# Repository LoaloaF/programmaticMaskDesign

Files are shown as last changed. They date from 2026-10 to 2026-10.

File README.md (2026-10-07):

# programmaticMaskDesign

Code that generates photomask layouts for the MEA1K flexible-electronics wafers: the
devices themselves, and their arrangement on a 100 mm wafer. Everything is generated from
parameters; nothing on a wafer is drawn by hand except where noted.

```
programmaticMaskDesign/
  MEA1K_wafer4_12x_8x_8x_breakoutboards_Rev2.gds   the fabricated interconnect wafer (Rev2)
  InterconnectGeneration/      MEA1K chip <-> Molex connector interconnects
    HANDOVER.md
    build_designs.py           all five wafer designs of a revision (Rev2, Rev3)
    WaferNesting/              interconnect wafers: nest, reproduce Rev2, build Rev3
      HANDOVER.md
  generative_probe_design/     flexible 64-channel electrode probes
    README.md
    electrode_bundle/HANDOVER.md
    WaferNesting/README.md     probe wafers: count-maximising nest, mark inversion, wafer map
```

| Project | Makes | Start with |
|---|---|---|
| `InterconnectGeneration/` | the 12-block / 8-block interconnect DXFs and the dummy test structures | [`InterconnectGeneration/HANDOVER.md`](InterconnectGeneration/HANDOVER.md) |
| `InterconnectGeneration/WaferNesting/` | interconnect wafers; rebuilds the Rev2 wafer geometry-identically | [`InterconnectGeneration/WaferNesting/HANDOVER.md`](InterconnectGeneration/WaferNesting/HANDOVER.md) |
| `generative_probe_design/` | electrode-probe DXFs from design specs, and their wafers | [`generative_probe_design/README.md`](generative_probe_design/README.md) |

## The fabricated wafer

`MEA1K_wafer4_12x_8x_8x_breakoutboards_Rev2.gds` — 4 × 12-block, 4 × 8-block `51_35`,
4 × 8-block `71_15`, 26 dummies. It is reproduced from `InterconnectGeneration/designs/`:

```bash
cd InterconnectGeneration
export WAFERNEST_CONFIG=config_rev2
KL=/Applications/KLayout/klayout.app/Contents/MacOS/klayout
$KL -b -r WaferNesting/01c_extract_exact_placements.py
$KL -b -r WaferNesting/01d_rebuild_wafer.py      # ends with GEOMETRY IDENTICAL
```

The GDS layer numbers on it are the hand-renumbered ones (Metal1 7, Polyimide_Negative +
EtchingPad 3, Etching + Via 5, Metal2 6); see `InterconnectGeneration/WaferNesting/HANDOVER.md` §4.2.

## Rev3

The same wafer — every piece at its Rev2 position — with a revised pad stack on all five
designs: the final PI etch is no longer one square per pad but 5 µm etch vias around the pad
perimeter (15–20 µm apart, on layer 3), and a new **Metal3** layer repeats the pad squares
(layer 8, with the template's layer-8 alignment marks). Details:
`InterconnectGeneration/HANDOVER.md` §4.5 and `InterconnectGeneration/WaferNesting/HANDOVER.md` §4.3.

```bash
cd InterconnectGeneration
python3 build_designs.py --rev 3                 # designs/rev3/
WAFERNEST_CONFIG=config_rev2 $KL -b -r WaferNesting/01c_extract_exact_placements.py
WAFERNEST_CONFIG=config_rev3 $KL -b -r WaferNesting/01d_rebuild_wafer.py    # checked against Rev2
WAFERNEST_CONFIG=config_rev3 $KL -b -r WaferNesting/01e_overlay_wafers.py   # Rev2 + Rev3 overlay
```

Output: `InterconnectGeneration/WaferNesting/runs/wafer4_rev3/wafer_wafer4_rev3.gds`.

## Status: two projects, being merged

The two projects grew separately and overlap:

- **two WaferNesting forks** — near-identical setup and footprint stages; the interconnect
  fork has the seeded annealer and the exact-reproduce path, the probe fork the
  count-maximising nester, mark inversion and wafer map. They also disagree on alignment-mark
  polarity, which a merged version has to make a per-wafer setting.
- **duplicated geometry helpers** (`stroke_centerline_to_polygon`, circles, rectangles,
  DXF I/O) copied from a common ancestor, and two implementations of the same tangent-fillet
  **teardrop** pad (InterconnectGeneration's `lib/teardrop.py` is the more complete one).
- **different config styles**: dataclasses (`generative_probe_design`) vs module globals
  loaded by `lib/active.select()` (`InterconnectGeneration`).

Environment: Python packages in the base conda python (`/opt/anaconda3/bin/python3`, which
has gdstk for the dummy; the `dxf` env lacks it); KLayout 0.29 app for every GDS stage. The folder is a git repository; generated output (`WaferNesting/runs/`, `64Ch_4Shankdesigns/`) is ignored.

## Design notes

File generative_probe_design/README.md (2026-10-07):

# generative_probe_design — electrode bundles and wafer nesting

Two folders, one pipeline. `electrode_bundle/` computes a flexible electrode probe from
parameters and emits its CAD; `WaferNesting/` takes designs like that one, arranges as
many copies as fit on a 100 mm wafer, and writes the combined GDS for fab.

They are independent — you can nest any DXF, not just a bundle — but this is the path
they were built for:

```
electrode_bundle/            WaferNesting/
  design_sets.py               config_64ch_4shank.py
      │                              │
      ▼                              ▼
  <TARGET_SET>/shanks/  ─────►  <TARGET_SET>/wafer/
   the probe geometry            as many as fit, nested, fab-ready
```

Full detail lives in [`electrode_bundle/HANDOVER.md`](electrode_bundle/HANDOVER.md) (the
generator) and [`WaferNesting/README.md`](WaferNesting/README.md) (the nester). Read those;
this page is only the map and the order to do things in.

> **Before anything is fabricated**, read the layer map at the bottom of
> [`WaferNesting/README.md`](WaferNesting/README.md). The DXF-layer → fab-layer mapping is
> provisional and has one open decision in it (`ionp`).

---

## Layout

Two code folders side by side, and one **target folder per design set** holding both
halves of the output. The target folder's name lives in `electrode_bundle/config.py` and
`WaferNesting/config_64ch_4shank.py` as `TARGET_SET`; the two must agree.

```
generative_probe_design/      <- run everything from HERE
  README.md                   <- this page
  electrode_bundle/           <- the design generator (code)
    HANDOVER.md
    batch.py, design_sets.py, config.py, bundle.py, ...
    hooks/                    <- named insertion-hook specs
    designs/                  <- shipped ...Example sample files (not output)
    tests/
  WaferNesting/               <- the nester (code)
    README.md
    00_check_setup.py, 01_extract_footprints.py, nest_tiler.py,
    03_export_wafer.py, 04_verify_wafer.py, 05_map_wafer.py
    config_64ch_4shank.py, config_common.py, footprint_extract.py
    new_wafer_actually.GDS    <- wafer template, included
    marks_union.wkt           <- alignment marks, included
  changes_plan/               <- the design change list and the per-session briefs
  64Ch_4Shankdesigns/         <- the target folder (all generated output)
    shanks/                   <- DXFs, PNGs, per-design JSON
    wafer/                    <- footprints, poses, preview, wafer GDS, wafer map
```

**Run every command from this folder**, not from inside either subfolder. Both tools
depend on it: `python3 -m electrode_bundle.batch` needs the package's parent on the path,
and the stage scripts are invoked as `WaferNesting/<stage>.py`.

---

## Prerequisites

```bash
pip install ezdxf shapely numpy matplotlib pytest
```

(On the dev machine these live in the `dxf` conda env:
`source /opt/anaconda3/etc/profile.d/conda.sh && conda activate dxf`.)

Plus **KLayout** for nesting stages 03 and 04 (GDS work). `00_check_setup.py` looks for it
at `/Applications/klayout.app/Contents/MacOS/klayout` and
`/Applications/KLayout/klayout.app/Contents/MacOS/klayout`.

Check both halves before starting:

```bash
python3 -m pytest electrode_bundle/tests -q                       # 240 tests; slow, minutes
WAFERNEST_CONFIG=config_64ch_4shank \
  python3 WaferNesting/00_check_setup.py                          # resolves every path
```

`00_check_setup.py` changes nothing. If an input is missing it names the exact setting in
the exact file to edit, and lists the DXFs it can actually see.

---

## 1. Generate the designs

**The usual command.** Builds every design listed in `electrode_bundle/design_sets.py` —
four geometries (U1.6, U2.5, U4, U8) × four IONP barcodes each = 16 variants:

```bash
python3 -m electrode_bundle.batch
```

Everything lands in **`<TARGET_SET>/shanks/`**. Per geometry (`<name>`, e.g. `U4`):
`electrode_bundle_<name>.dxf` + `.png` (barcode-free), `electrode_to_flex_mapping_<name>.json`
and `<name>_electrodes.json`. Per barcoded variant (`<tag>`, e.g. `U4C08`):
`electrode_bundle_<tag>.dxf` + `.png` and `<tag>_info.json`. Plus two comparison drawings:
**`all_designs_side_by_side.dxf`** (every geometry in a row) and
**`all_ionp_patterns_side_by_side.dxf`** (all 16 barcoded variants in a row). Add
`--no-render` to skip the PNGs (much faster) or `--no-side-by-side` to skip the combined
DXFs.

To change what gets built, edit `_BASE_DESIGNS` in `electrode_bundle/design_sets.py`; its
docstring has a labelled diagram of every length parameter.

Rebuild a comparison drawing on its own, optionally for a subset:

```bash
python3 -m electrode_bundle.side_by_side              # all geometries
python3 -m electrode_bundle.side_by_side --ionp       # all barcoded variants
python3 -m electrode_bundle.side_by_side 1.6 U8       # name substrings
```

**One-off, scratch probe.** `main.py` builds a single probe from a bare `BundleConfig()`
(not one of the `DESIGNS`), with a barcode:

```bash
python3 -m electrode_bundle.main all --pattern-i 11
```

Writes `64Ch_4Shankdesigns/shanks/electrode_bundle_C11.dxf` plus its preview and
`64ch_C11_info.json`. Details: [`electrode_bundle/HANDOVER.md`](electrode_bundle/HANDOVER.md) §1.

> The files in `electrode_bundle/designs/` carry an **`Example`** suffix and are shipped
> samples from an earlier generation of the generator. They are not reproduced by any
> command and nothing reads them — `config_64ch_4shank.py` nests the real generated designs
> in `<TARGET_SET>/shanks/`, so run the generator first.

## 2. Nest it onto a wafer

```bash
export WAFERNEST_CONFIG=config_64ch_4shank
KL=/Applications/KLayout/klayout.app/Contents/MacOS/klayout

python3 WaferNesting/00_check_setup.py
python3 WaferNesting/01_extract_footprints.py
python3 WaferNesting/nest_tiler.py --time 900
# paste the SHANK_COUNTS line it prints into the config, then:
$KL -b -r WaferNesting/03_export_wafer.py
$KL -b -r WaferNesting/04_verify_wafer.py
python3 WaferNesting/05_map_wafer.py
```

Which designs and in what ratio is set at the top of
`WaferNesting/config_64ch_4shank.py`. Output lands in `64Ch_4Shankdesigns/wafer/`; the
deliverable is `wafer_64Ch_4Shankdesigns.gds`, `nest_preview.png` shows the arrangement
(refreshed live while the search runs), and `wafer_map_64Ch_4Shankdesigns.png` labels every
device with its variant.

Stage 04 should end with `ALL CHECKS PASSED`. Stage 03 refuses to overwrite an existing
wafer GDS — delete it (or change `RUN_TAG`) to re-export.

---

## Two things worth knowing up front

**The piece count is an output, not an input.** The config's `SHANK_RATIO` is read only as
a *ratio*; `nest_tiler.py` fills the wafer and reports how many fit — 59 at 74 % density
for the current 64-channel set. Because of that, `SHANK_COUNTS` in the config has to be
updated from the nester's printed line before exporting, or stage 03's count assertion
trips.

**A DXF layer missing from `LAYER_MAP` is silently deleted on export.** Stage 03 prints
what it mapped and what it dropped on every run — read that output. Stage 04's per-layer
shape-count check is the backstop.

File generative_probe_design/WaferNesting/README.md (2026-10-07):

# WaferNesting — how to nest a design set onto a wafer

Takes design DXFs, finds the densest legal arrangement on a 100 mm wafer, and writes the
combined GDS for fabrication. **One config file drives the whole run** — the stage scripts
hold no paths, clearances or layer names of their own.

> **Before anything is fabricated, read "Layer map" at the bottom.** The layer mapping is
> provisional and has one open question in it.

For the pipeline as a whole (generator → wafer), start at [`../README.md`](../README.md); the
generator that produces the DXFs nested here is documented in
[`../electrode_bundle/HANDOVER.md`](../electrode_bundle/HANDOVER.md).

---

## Layout

One target folder per design set, holding **both** halves of the pipeline:

```
generative_probe_design/
  electrode_bundle/            <- the design generator (code)
  WaferNesting/                <- this folder (code)
  64Ch_4Shankdesigns/          <- the target folder
    shanks/                    <- generator output: DXFs, PNGs, per-design JSON
    wafer/                     <- nesting output: footprints, poses, preview, wafer GDS
```

The folder name lives in exactly two places, and they must agree:

| File | Constant |
|---|---|
| `electrode_bundle/config.py` | `TARGET_SET = "64Ch_4Shankdesigns"` |
| `WaferNesting/config_64ch_4shank.py` | `TARGET_SET = "64Ch_4Shankdesigns"` |

Keeping both halves under one folder is the point: a wafer can never be built from shanks
that live somewhere else.

---

## Running it

```bash
cd generative_probe_design
export WAFERNEST_CONFIG=config_64ch_4shank
KL=/Applications/KLayout/klayout.app/Contents/MacOS/klayout

python3 -m electrode_bundle.batch            # 1. shanks  -> 64Ch_4Shankdesigns/shanks/
python3 WaferNesting/00_check_setup.py       # 2. resolve every path, check packages
python3 WaferNesting/01_extract_footprints.py#    DXF -> collision silhouette
python3 WaferNesting/nest_tiler.py --time 900#    silhouettes -> poses.json  (the nest)
# paste the SHANK_COUNTS line it prints into the config, then:
$KL -b -r WaferNesting/03_export_wafer.py    # 3. poses + DXFs -> wafer GDS
$KL -b -r WaferNesting/04_verify_wafer.py    #    re-check the GDS against the sources
python3 WaferNesting/05_map_wafer.py         # 4. the wafer map: what is where
```

**Start with `00_check_setup.py`.** It resolves every path the config depends on, checks
the Python packages and KLayout, lists the DXFs actually present, and on failure names the
exact setting to edit. It changes nothing.

| Stage | Does | Needs |
|---|---|---|
| `00_check_setup.py` | verifies the install and every input path | python3 |
| `01_extract_footprints.py` | design DXF → silhouette + centroid offset | python3 + shapely |
| `nest_tiler.py` | silhouettes → poses `[kind, angle, x, y]`, maximising the count | python3 + shapely |
| `03_export_wafer.py` | poses + **original DXFs** → wafer GDS | KLayout |
| `04_verify_wafer.py` | re-checks the wafer against the sources | KLayout |
| `05_map_wafer.py` | `placement.json` → labelled map PNG | python3 + matplotlib |

### Outputs — all land in `<TARGET_SET>/wafer/`

| File | What |
|---|---|
| `footprint_<key>.json` + `_offset.json` | per design variant: silhouette (centred) and the centroid to undo it |
| `envelope_<kind>.json` | per geometry: the union of its variants' silhouettes, which is what the nester packs |
| `footprints_overlay.png` | visual check of every silhouette |
| `poses.json` | `[kind, angle_deg, x_mm, y_mm]` per piece |
| `nest_report.json` | per-piece kind / pose / radial reach, plus run settings |
| `nest_preview.png` | the nest, with wafer rim, usable radius and marks |
| `wafer_<TARGET_SET>.gds` | **the deliverable** |
| `wafer_<TARGET_SET>.oas` | the same layout in OASIS, which stores the layer names in-file |
| `wafer_<TARGET_SET>.lyp` | layer names for KLayout (GDS2 cannot store them) |
| `placement.json` | which design variant stage 03 put at which pose |
| `wafer_map_<TARGET_SET>.png` | **the map** — every device coloured, numbered and named |

`nest_tiler.py` refreshes `nest_preview.png` **every time the record improves**, so it can
be watched live while the search runs. Useful flags:

```
--time 900     wall-clock budget in seconds (the search plateaus; more time stops helping)
--trials 400   cap on restarts
--gap 0.05     mm between devices (default 0 -- they may touch)
--edge 2.0     mm edge exclusion (default: the config's EDGE_EXCL)
--stride 1     finer candidate x positions (slower)
--seed 7       change this if a run looks unlucky
```

---

## Nesting a *new* design set

1. **Generate the shanks.** Set `TARGET_SET` in `electrode_bundle/config.py`, add your
   geometries to `electrode_bundle/design_sets.py`, run `python3 -m electrode_bundle.batch`.
2. **Copy `config_64ch_4shank.py`** to `config_<your_set>.py` and edit, in order:
   - `TARGET_SET` — must match step 1.
   - `SHANK_RATIO` — one entry per design, keyed by the DXF's name. **This is the mix the
     nester aims for**; only the proportions matter.
   - `SHANK_COUNTS` — the *result* of the last nest, pasted from the nester's printed
     line. Only `03_export_wafer.py`'s count assertion reads it.
   - `IONP_VARIANTS` — the barcoded variants of each geometry. `DESIGNS` is built from
     `SHANK_COUNTS` × these, so the filenames must match what the generator wrote.
   - `LAYER_MAP` / `LAYER_NAMES` / `MARK_LAYERS_UNUSED` — see the layer map below. These
     depend on which alignment slots your wafer template carries.
3. `export WAFERNEST_CONFIG=config_<your_set>` and run the pipeline above.

Nothing is searched for. Each config states its input locations explicitly in its `PATHS`
block, and `00_check_setup.py` names the line to edit when something is missing.

---

## How the nester works

The piece count is the **objective**, not an input: the config's counts are read only as a
ratio, and the nester fills the wafer and reports how many fit. On the 64-channel 4-shank
set it seats **59 pieces at 74 % density** (22 × U4, 15 × U1.6, 14 × U2.5, 8 × U8).

**Flip 180°.** Each design is a "sword" — a 3.01 mm handle ~13 mm long, a 2.06 mm shank, a
1.72 mm neck, then a taper to a point. A copy rotated 180° puts a handle against a tip, so
a flipped stack packs at **2.66 mm pitch instead of 3.46 mm, 23 % tighter**. This is
measured from your actual footprints and printed at the top of every run — if a redesign
changes the silhouette, the number moves with it.

**The lattice is not hard-coded.** Pieces are dropped one at a time onto an exact skyline;
the flipped orientation simply *falls lower* into its neighbour's taper, so the interlock
emerges by itself. Unlike a fixed lattice it also follows the wafer's curvature and mixes
designs of different lengths freely — worth ~5 pieces over a flat-row lattice at the same
pitch.

Everything written has passed a re-check against the true polygons: zero overlap, inside
the usable radius, clear of the alignment marks.

---

## The wafer map

`05_map_wafer.py` draws the wafer with every device coloured by geometry, shaded by barcode
variant, and labelled with its number and variant code. The legend lists each variant's
device numbers, so it reads in both directions: point at a device to find out what it is,
or look up a variant to find where its copies are.

It draws from **`placement.json`, which stage 03 wrote** — not from a recomputed
assignment. The variant→pose deal is a seeded shuffle, and a second implementation of it
would be free to disagree with the GDS that actually shipped; a map that mislabels a device
is worse than no map. Stage 04 cross-checks the two, comparing every instance's cell, angle
and position, and fails if they differ. So the order matters: **03, then 04, then 05.**

Labels sit on each device's wide handle rather than its centre. The centre is in the narrow
shank, where the flipped neighbour's handle is interlocked right against it — the most
crowded part of the picture. Handles of adjacent pieces point in opposite directions, so
anchoring there spreads the labels apart.

---

## Things that will bite you

1. **Any DXF layer missing from `LAYER_MAP` is silently deleted on export.** No warning,
   no error — the geometry simply is not in the GDS. This is the pipeline's most likely and
   least visible failure, and it is how `EtchingPad` was nearly lost on the 2026-07 wafer.
   Stage 03 prints the mapped and dropped lists per design; **read them.** Stage 04's
   per-layer count check is the backstop.
2. **`03_export_wafer.py` asserts `len(poses) == sum(SHANK_COUNTS.values())`.** The nester
   does not know your config's counts, so paste the `SHANK_COUNTS = {...}` line it prints
   into the config before exporting. `SHANK_RATIO` is what it aims for and is deliberately
   separate — if the nester took its mix from `SHANK_COUNTS`, pasting each result back
   would drift the mix a little further every run.
3. **Never reuse poses because the footprint "did not change".** Regenerated designs once
   differed by 0.2–1.0 mm² — visually identical — and that was enough to drop the old poses
   to a 0.0002 mm gap. Re-run `01` and the nester whenever a DXF changes.
4. **The footprint must not under-cover.** It is a collision proxy: the union of *every*
   layer, closed by `CLOSE_GAP` and simplified by `SIMPLIFY`. Simplification that cuts
   inside the true outline lets pieces overlap in the GDS while the nest reports success.
   Check `footprints_overlay.png`.
5. **`ENVELOPE_SIMPLIFY` must stay ≤ `ENVELOPE_PAD`**, or the envelope shrinks inside the
   designs it is supposed to contain.
6. **Never nest the plain `electrode_bundle_<kind>.dxf`.** It carries no IONP layer, so the
   magnetic ID would be missing from every device and layer 1/0 would ship as marks only.
   The config nests the barcoded `C00`–`C15` variants for exactly this reason.
7. **The clearances are measurements, not preferences.** `EDGE_EXCL 3.0` / `GAP 0.05` /
   `MARK_BUF 0.7` are what the fabricated 2026-07 wafer actually honours (measured: edge
   2.993 mm, inter-piece 0.000 mm, mark 0.701 mm). `EDGE_EXCL` in particular is *precedent,
   not a fab spec* — relaxing it packs more (2.0 mm → 62, 1.0 mm → 64), but that is a yield
   question for the fab, not a geometry one, and the electrodes sit 0–4 mm from the tapered
   tip with the bond pads at the far end, so no part of a shank is sacrificial.
   Note that `nest_tiler.py` does **not** read `GAP`: it defaults to 0 (pieces may touch)
   and takes `--gap` on the command line.
8. **`03_export_wafer.py` refuses to overwrite an existing wafer GDS.** Delete
   `wafer_<TARGET_SET>.gds` (or change `RUN_TAG` in the config) before re-exporting — and
   then re-run 04 and 05, since both read what 03 wrote.

---

## Layer map — CONFIRM BEFORE FABRICATION

**The wafer template is not a backdrop.** `new_wafer_actually.GDS` already carries the
alignment marks, and every target layer in `LAYER_MAP` is one of those mark layers — so a
device layer and its own alignment mark ship as a **single mask**. Stage 03 merges them.

The mark cluster (mirrored at both |x| ends) holds five slots. Each slot pairs one layer's
mark with a `7/0` companion, and `7/0` appears in *every* slot: it is the reference
everything else aligns to, which is why metal — the first mask — lives there.

| slot, \|x\| from centre | template layer | mark | used for |
|---|---|---|---|
| 40.94 – 41.47 mm | `6/0` | fine cross, 129 polys → **inverted on export** | **Etching** |
| 41.62 – 42.17 mm | `3/0` | **inverted** vernier, 1 poly + 129 holes | **pad_etching** (already the right polarity) |
| 42.34 – 42.87 mm | `8/0` | fine cross, 129 polys → **inverted on export** | **PEDOT_SIROF** |
| 43.04 – 43.57 mm | `1/0` | fine cross, 129 polys → **inverted on export** | **IONP** |
| 43.72 – 44.27 mm | `5/0` | **inverted** vernier, 1 poly + 129 holes | the **stencil** every dark-field mask's mark is copied from — dropped on export |

### Mask polarity, and why the marks are inverted

**Metal is the first mask and the only bright-field one.** Its plate is chrome where the
drawn shapes are, and it is what puts the alignment marks on the wafer — every later mask is
aligned to those. Every later mask is **dark field**: chrome everywhere except the drawn
shapes, which are the openings. That is already right for the device geometry (what we draw
is what gets opened), but it is *not* right for a mark drawn as 129 separate bars: those
print as 129 slits in a chrome field, and the metal scale they have to be read against is
under that chrome, invisible.

So every dark-field mask needs the **inverted** vernier — one polygon with the bars as holes,
which prints as a clear window with the scale in chrome and the metal mark showing through.
The template ships that form on `3/0` and `5/0` only. Stage 03 therefore copies the `5/0`
mark into the `6/0`, `8/0` and `1/0` slots (`MARK_INVERT_LAYERS`), **registered on the `7/0`
metal companion** that sits in every slot — not on the mark's own bounding box, because the
two ends of the wafer are not mirror images and the mark sits a different fraction off its
companion on each side. Each band is handled with its own band's stencil.

The transform is proved on every run before it is used: `3/0`'s inverted mark is rebuilt from
the `5/0` stencil and must reproduce the template's own geometry exactly (XOR = 0), or stage
03 aborts. Stage 04 then re-checks the finished GDS by area, per band, and fails if any
dark-field mark is not inverted or if a metal mark *is*.

`LAYER_MAP`, DXF layer name (lower-cased) → (GDS layer, datatype):

| DXF layer | GDS | What |
|---|---|---|
| `metal` | 7/0 | single-metal design + the design-ID markings; **the alignment reference** |
| `etching` | 6/0 | device release: outline, the insertion loop's hole, the solder pads |
| `pad_etching` | 3/0 | the site openings — 13.5 µm circles onto the gold, recording and reference. A **solid-box** mark, the coarser of the template's two styles, against a ~1.75 µm alignment budget to the metal (13.5 µm opening in a 17 µm pad): if that proves too tight, trade with a fine-cross layer, not with the remaining box at `5/0` |
| `pedot_sirof` | 8/0 | the PEDOT/SIROF coating, 15 µm circles in the 13.5 µm openings |
| `ionp` | 1/0 | the IONP wells — **assumed etched features. This is the one to confirm.** |

Dropped on purpose, because they are documentation geometry rather than process steps:
`polyimide` (the positive body; fab uses the negative `etching`), `electrodes` and
`ref_electrodes` (the contact centres — already cut by `pad_etching`; they must not become
mask features), plus the DXFs' empty CAD layers `0` and `defpoints`.

Stage 03 also cleans the template: it deletes the **third copy of the whole mark cluster**
that sits near x = +96 mm, far outside the 100 mm wafer, and the one remaining unused mark
layer (`5/0`, since `pad_etching` took `3/0`) — but only *after* `5/0` has donated its
inverted vernier to the dark-field masks, see below. The delivered GDS contains exactly six
layers — five masks plus the wafer outline.

### Layer names, and the three files stage 03 writes

The layers are named after the DXF layers they came from — `Metal`, `Etching`,
`PEDOT_SIROF`, `IONP`, plus `WaferOutline`. How far a name travels depends on the format,
not on KLayout, so stage 03 writes three files:

| file | what it is |
|---|---|
| `wafer_<TARGET_SET>.gds` | the deliverable. **GDS2 has no layer-name record** — there is no writer option for one, and a layout written with names and read back comes out unnamed. Layers here are `7/0`, `6/0`, … only. |
| `wafer_<TARGET_SET>.oas` | the same layout in OASIS, which *does* have a `LAYERNAME` record. Open this if you want the names in the file itself. |
| `wafer_<TARGET_SET>.lyp` | KLayout layer-properties sidecar that names the GDS's layers. *File → Load Layer Properties*. |

The GDS is written with `gds2_max_vertex_count = 4000`. The merged `Etching` mask is one
~20 000-vertex polygon per design, and GDS2 caps a `BOUNDARY` at 8191 points with a record
length held in a **signed** 16-bit int, i.e. 32 KB. Unsplit, KLayout reads its own file back
complaining that the record length must be reinterpreted as unsigned, and a stricter reader
at the fab may simply reject it. The cap splits those polygons into abutting pieces; the
union is unchanged (XOR against the OASIS twin is entirely sub-nanometre seam slivers that
vanish under a 1 nm shrink).

### The magnetic-ID (IONP) variants

Each geometry exists as **four** barcoded variants — `U1.6C00–C03`, `U2.5C04–C07`,
`U4C08–C11`, `U8C12–C15`. The plain `electrode_bundle_<kind>.dxf` has **no IONP layer at
all**, so it must never be nested for a real wafer. `IONP_VARIANTS` in the config lists
them; the config splits each kind's count evenly across its four, and stage 03 deals them
onto that kind's poses in a seeded shuffle so a variant is spread over the wafer rather
than correlating with the order the nester happened to seat them. `VARIANT_SEED` makes a
re-run reproduce the same wafer.

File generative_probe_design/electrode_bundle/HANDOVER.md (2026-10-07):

# electrode_bundle — handover

Parametric generator for the 64-channel flexible electrode probe (MEA1K connector project).
You give it numbers, it emits the CAD. **Nothing is drawn by hand and no input file is required**
— the entire device geometry is computed from `design_sets.py` + `config.py`.

All generated output goes to **`<TARGET_SET>/shanks/`** (`TARGET_SET` in `config.py`;
currently `64Ch_4Shankdesigns`) — a sibling of this folder, not inside it. The path is
resolved from the module's own location, so nothing needs editing on a new machine. The
only things inside `designs/` are shipped `…Example` sample files from an earlier
generation; nothing reads them.

For the pipeline as a whole (generator → wafer), start at [`../README.md`](../README.md).

---

## 1. Quickstart

```bash
pip install ezdxf shapely matplotlib numpy pytest

cd <the folder CONTAINING electrode_bundle/>     # not into electrode_bundle itself
python3 -m electrode_bundle.batch                # every design in design_sets.DESIGNS
python3 -m pytest electrode_bundle/tests -q      # 240 tests; ~15 min (every build solves)
```

> Run from the **parent** of `electrode_bundle/` — that's how `python3 -m electrode_bundle.<x>`
> resolves the package. There is nothing to install and no path to edit.

### Entry points

| Command | Does |
|---|---|
| `python3 -m electrode_bundle.batch` | **the usual one.** Builds all 16 `DESIGNS` variants + the two comparison DXFs. `--no-render`, `--no-side-by-side` |
| `python3 -m electrode_bundle.side_by_side [names] [--ionp]` | rebuilds a comparison DXF from already-generated files. `--align loop\|top`, `--gap`, `--out` |
| `python3 -m electrode_bundle.plot_bundling [names] [--theta] [--bundle-ratio]` | per design: flat vs bundled contact positions → `<name>_bundling.png` |
| `python3 -m electrode_bundle.ionp_patterns` | prints the design × IONP-pattern fit matrix |
| `python3 -m electrode_bundle.main <cmd>` | single scratch probe from a bare `BundleConfig()` — see below |

`main.py` subcommands, all on the bare default config (which is **not** one of the
`DESIGNS`: it carries the dense `{33..48: 30.0}` spacing band and no design label):

| Subcommand | Does | Reads a file? |
|---|---|---|
| `bundle`  | electrode bundle DXF + preview PNG (`electrode_bundle.dxf`) | no |
| `mapping` | channel → flex-PCB pad JSON (`electrode_to_flex_mapping.json`) | no |
| `ionp` | stamps IONP wells onto an **existing** `electrode_bundle_C{NN}.dxf` (in place) | **yes** — see §7 |
| `all` | all three in a single in-memory pass | no |
| `legend`  | decode reference card for all 16 IONP ids (`ionp_id_legend.png`) | no |

Flags: `--pattern-i 0-15` (IONP id, sets the output filenames `C{NN}`), `--no-render`.

### Outputs of `batch` — all land in `<TARGET_SET>/shanks/`

Created automatically on first run. `<name>` is the geometry (`U1.6`, `U2.5`, `U4`, `U8`);
`<tag>` is `config.variant_tag(name, id)`, e.g. `U4C08` — the same string that is etched
into the gold as the design label.

| File | What |
|---|---|
| `electrode_bundle_<name>.dxf` + `.png` | the geometry, **no** IONP layer — never nest this |
| `electrode_to_flex_mapping_<name>.json` | channel → flex-PCB pad number |
| `<name>_electrodes.json` | per-channel wafer **and** bundled positions, lengths, fold model (`probe_json.py`) |
| `electrode_bundle_<tag>.dxf` + `.png` | the geometry **plus** its IONP barcode — what WaferNesting nests |
| `<tag>_info.json` | per-stripe IONP metadata, with the flex mapping embedded |
| `all_designs_side_by_side.dxf` | every geometry in a row, barcode-free, aligned on the loop |
| `all_ionp_patterns_side_by_side.dxf` | all 16 barcoded variants in a row |

Re-running **overwrites in place**. Every DXF goes through `dxf_io.save_dxf`, which strips
the build-only layers (`config.EXPORT_DROP_LAYERS`: `Electrodes`, `Ref_Electrodes`,
`Polyimide`) — see §2.2.

---

## 2. Architecture

### 2.1 Data flow — one producer, several consumers

```
design_sets.DESIGNS                       DesignSpec: name, n_channels, sites, fiber_length,
   │                                      loop_offset, overall_length, ionp_pattern_id
   ▼
batch.config_for(spec) ──► BundleConfig
   │  spacing.Uniform/Segments  → delta_y / delta_y_overrides
   │  design_sets.BUNDLE_FOLD    → shoulder_offsets_profile (per-fiber shoulder stagger)
   │  lengths.solve_lengths      → hook_drop, then bottom_elec, to hit loop_offset / fiber_length
   │  overall_length             → ribbon_length
   ▼
bundle.build_bundle(cfg) ──► BundleResult (doc, electrode_locs, ref_locs, chan_pad, loop_xy, …)
   ├──► mapping.build_mapping     channel → flex pad
   ├──► ionp.add_ionp_wells        IONP barcode wells onto the same doc
   └──► probe_json.build_record    <name>_electrodes.json
```

The bundle is built **once** per variant and its in-memory result handed to every consumer,
so the mapping never re-derives the routing order and IONP never re-reads the DXF.

| Module | Role |
|---|---|
| `design_sets.py` | **What to build.** `_BASE_DESIGNS` (one per geometry) × `ionp_patterns.DESIGN_IDS` → `DESIGNS`. Also `BUNDLE_FOLD` and `FAMILY_OVERALL_LENGTH`. Its docstring has the labelled length diagram |
| `config.py` | **How it is built.** `BundleConfig`, `IonpConfig`, `MappingConfig`, `RefSpec`/`REF_SITES`, `TARGET_SET`, `variant_tag`, `EXPORT_DROP_LAYERS`, `LOOP_DATUM_VAR` |
| `batch.py` | spec → config → build → write; the main entry point |
| `spacing.py` | `Uniform(span)` / `Segments(runs)` site layouts → `delta_y` kwargs |
| `lengths.py` | `measure` and `solve_lengths` — the doc's lengths ↔ config knobs (§3.2) |
| `bundling.py` | flat → bundled positions: `TwoArcFold` (from electrode2geometry), `NoFold` |
| `bundle.py` | `build_bundle(cfg)` assembles the DXF; `render_bundle` draws the preview |
| `shapes.py` | device shapes: site outlines, fanout body, pad columns, `assign_channels_to_pads`, `build_pad_routes` (incl. the Ref wrap route), `fiber_x_positions`, text outlines |
| `geometry.py` | generic primitives (arcs, S-transition, stroked centrelines) — knows nothing about electrodes |
| `hooks/` | insertion-hook specs, one named spec each (`teardrop_clap` = current, `legacy_barb` = archived). Each owns its outline **and** its etch hole |
| `mapping.py` | channel → flex-PCB pad assignment |
| `ionp_patterns.py` | the frozen IONP barcode bank `IONP_PATTERNS` + `DESIGN_IDS` + validation |
| `ionp.py` | stamps a pattern onto a geometry and enforces the design rules (§5) |
| `probe_json.py` | the per-design electrode record |
| `side_by_side.py`, `plot_bundling.py`, `id_legend.py` | inspection drawings |
| `dxf_io.py` | DXF readers/writers; `save_dxf` strips build-only layers |
| `main.py` | single-probe CLI (§1) |
| `tests/` | pytest suite (§6) |

To change a design, edit its `DesignSpec`. To change how every design is built, edit a
default in `config.py` **or** pass overrides: `BundleConfig(hook_drop=300)`.

### 2.2 Layers

| DXF layer | Exported? | What |
|---|---|---|
| `Metal` | yes | all gold: site pads + wires, the Ref trace and contacts, routes, solder pads, design labels |
| `Etching` | yes | **device release**, through the whole stack: the moat, the tip wedge, the insertion loop's hole, and every solder-pad opening (a 200 µm circle in the 220 µm gold, `pad_opening_inset` of collar) |
| `pad_etching` | yes | **site openings**, through the top polyimide only: the 13.5 µm circle over every recording site and every Ref contact. Never anything else |
| `PEDOT_SIROF` | yes | the 15 µm coating circles, concentric with the openings |
| `IONP` | yes | the barcode wells (barcoded variants only) |
| `Electrodes` | **dropped on save** | the 64 recording openings again — the build and tests read contact centres off it |
| `Ref_Electrodes` | **dropped on save** | the Ref openings again, kept OFF `Electrodes` so they never redefine the array |
| `Polyimide` | **dropped on save** | the positive body; the fab patterns the negative (`Etching`) |

### 2.3 Device geometry, tip to connector

- **Electrode site** — four concentric circles: `l_contact` 13.5 (opening), `l_pedot` 15
  (coating), `l` 17 (gold pad), `2·polyimide_pad_r` 25 (polyimide swelling). Each blends
  into its trace with tangent fillets. Every recording fiber ends `polyimide_tip_len`
  (100 µm) below its own site in a tapered tip.
- **Fibers across the shank** — there are **65**: fiber 0 is the **Ref**, on the centre
  slot (x = 0), widened to `wide_wire_hw`, and carrying the hook; recording channel `c` is
  fiber `c+1` and the channels alternate outward (ch0 on +x next to the Ref, ch1 on −x, …).
  `shapes.fiber_x_positions` is the layout; `batch._fiber_x` must agree with it.
- **Insertion hook** (`hooks/teardrop_clap.py`, from `changes_plan/new_hook.png`) — a
  teardrop head with 6 claps (5 µm arms) and one 35 × 45 µm elliptical etch hole: the
  **loop**, the probe's depth datum (§3.2). `build_bundle` asserts ≥ `hook_etch_margin`
  (8 µm) of polyimide around it.
- **Shoulder** — each fiber is freed from the polyimide block at its own height,
  `BUNDLE_FOLD.offsets(x)` above the base, so outer fibers get the extra free length they
  need to swing into the bundle. The block's lower edge is therefore a staggered curve.
- **Fanout / routes** — every channel runs a neck, a gather fan into a centred 25 µm-pitch
  bundle, a vertical riser and one 50° diagonal into its pad (`build_pad_routes`).
- **Solder-pad block** — `polyimide_width` 2.85 mm, entered through an S-transition
  (`polyimide_curve_height`, clamped to the available stem). Two half-disc alignment tabs
  (0.6 mm left, 0.3 mm right) are the orientation indicator: the **big** tab marks the
  edge **away** from the Ref's column.
- **Solder pads** — 2 columns × 33 at x = ±975, `pad_pitch` 300, `pad_diam` 220. Each
  wired pad is a **teardrop** aimed back along its route (`pad_teardrop_fillet_radius`
  275; **295 is the wall** — beyond it adjacent lanes close up, at 400 they short, which
  `test_pad_teardrops_keep_the_metal_spacing` pins). Row 0 of each column is a flex REF/GND
  pad: the Ref takes the **right** one (flex 66, `shapes.REF_PAD`); the left one is the
  device's single spare, an unrouted plain circle.
- **Design label** — `variant_tag` text in `Metal`, twice: small (`label_tip_height`) beside
  the Ref's bottom contact band (on the carrier, for processing), and large
  (`label_pad_height`) above the pad field, **mirrored** because the finished device is read
  from the other face. `label_pad_x/y` place it by hand; there is no fit check.

---

## 3. The ideas worth understanding

### 3.1 Electrode depths are a cumulative-gap staircase

The gap *before* channel `i` is `delta_y`, overridable per channel via
`delta_y_overrides = {i: µm}`. Positions are the **cumulative sum** of gaps, so editing one
gap shifts every electrode above it and leaves everything below untouched.

Designs normally don't touch these directly: `spacing.Uniform(span)` sets
`delta_y = span/(n-1)` with no overrides, and `spacing.Segments([(start, end, pitch), …])`
sets every gap explicitly in the 1-indexed, inclusive notation design docs use. The bare
`BundleConfig()` default (what `main.py` builds) carries a dense band `{33..48: 30.0}`.

**Anchor — which end stays put.** The staircase is built bottom-up, so the **deep tip
(channel 0) is pinned** and the shallow end absorbs every change. With the default band the
array spans 6448.25 µm instead of 8000 and the shallow end sits 1551.75 µm lower. There is
deliberately no `spacing_anchor` option: pinning the shallow end instead is a rigid offset,
reachable with `bottom_elec -= sum(delta_y - new_gap)`. Within `batch` the question is moot
anyway — `solve_lengths` re-places everything off the loop.

### 3.2 Lengths are solved, not computed

`DesignSpec` states the lengths as the design doc does (diagram in `design_sets.py`):

```
loop_offset + sites.span + (free fiber) = fiber_length       (loop -> shoulder)
fiber_length + (ribbon)                 = overall_length     (loop -> first solder pad)
```

`lengths.solve_lengths` hits `loop_offset` by moving `hook_drop`, then `fiber_length` by
moving `bottom_elec`: build once, measure, add the residual, rebuild, assert within 0.05 µm.
That works only because both relations are **linear with slope 1** in their knob — so a hook
spec must move its etch hole down by **exactly** `drop` (the `drop` contract in
`hooks/__init__.py`). `overall_length` then sets `ribbon_length`, so probes with different
fibers still end at the same connector position.

The datum is the loop centre, `BundleResult.loop_xy`, taken from the hook spec (the hole now
lives inside the single `Etching` mask, so no layer holds it alone). `build_bundle` also
stamps it into the DXF header as `LOOP_Y_UM` (`config.LOOP_DATUM_VAR`); `side_by_side`
aligns saved designs on it.

A `loop_offset` shorter than the fiber's own overhang below the deepest site
(`polyimide_pad_r + 250` = 262.5 µm) drives `hook_drop` **negative** — the head is pulled up
into the trace. That is legal (U2.5 asks for 250).

### 3.3 Bundling: drawn vs implanted positions

The probe is made flat and then gathered into a bundle. `bundling.TwoArcFold` (after
Gombkoto's electrode2geometry, MIT) models each fiber's sideways run as two arcs at constant
arc length; the loss of reach depends only on |x| — zero on the Ref, largest on the
outermost fibers (~287 µm with today's settings).

It is used in two places:

- **in the drawing** — as the per-fiber shoulder stagger (§2.3), so outer fibers get the
  free length they need. Contacts are still drawn exactly where `sites` says.
- **in the record** — `<name>_electrodes.json` carries each channel's `wafer` position and
  its modelled `bundled` position, and the bundled site span (array stretches by ~287 µm).

`max_theta_deg` (50°) is **not calibrated** against a real bundled device and dominates the
result (~60 µm per 10°). The JSON says `"calibrated": false` next to the numbers.

### 3.4 The reference electrode on the centre fiber

The centre fiber is not a recording channel: it is the Ref, carrying many parallel
contacts (`config.RefSpec`, shared by every design as `REF_SITES`):

- a **bottom band** starting `tip_offset` (150 µm) below the deepest recording site and
  stepping `pitch` (23 µm) down for as long as the next contact still lands on gold. The
  Ref's gold runs down the hook stem to `metal_loop_clearance` (20 µm) above the loop hole,
  so a longer `loop_offset` simply buys more contacts (U2.5 at 250 µm gets ~3; the 500 µm
  designs ~14);
- a **top band** starting `top_offset` (230 µm) above the shallowest site and running
  `top_len` (1000 µm) up the free fiber.

`RefSpec.check` raises on a band that would leave the gold, touch the recording array or
pass the fiber's top. The Ref trace is 4 µm wide (recording traces: 2 µm).

**Routing.** Outer-lane → lowest-pad is the **only** crossing-free ordering for this
riser-plus-diagonal topology on one metal layer, and the Ref (innermost lane) needs the
lowest pad (row 0). So it goes over the top: up the centre lane past the whole pad field,
across, down the empty corridor outside the right column, into row 0 from the side
(`shapes._build_ref_wrap_route`, shape knobs `BundleConfig.ref_wrap_*`, every clearance
asserted against `ref_wrap_clearance` = 100 µm).

**Kept apart on purpose.** Ref contacts live in `BundleResult.ref_locs` and on
`Ref_Electrodes`, never in `electrode_locs` / `Electrodes`. Everything downstream treats
`electrode_locs` as "the array" — `lengths.measure` reads the span and loop offset off it,
IONP normalizes against it, `probe_json` reports it — so a Ref contact in there would
silently redefine all three. `assign_channels_to_pads` gets recording channels only.

### 3.5 The IONP barcode is a fixed bank on a shared slot grid

Each barcoded variant carries an MRI-readable stripe pattern of 1.5 µm iron-oxide wells
encoding a **pattern id 0–15**. The patterns are **frozen data** in
`ionp_patterns.IONP_PATTERNS`, not computed per design.

- Coordinates are normalized **along the electrode array, not the whole shank**: `0` = the
  deepest site (ch0), `1` = `id_top_margin` (**120 µm**) above the shallowest site. On the
  current designs that range is **1758 / 2639 / 4057 / 7993 µm** (U1.6 / U2.5 / U4 / U8).
- Every pattern has a **tip anchor** (`0 → 0.2438`, always the fattest stripe, so it
  doubles as the orientation cue) and a **top anchor** near `1`. The anchors bracket the
  array, so their separation identifies the design; the data stripes between them give the
  id within it.
- Data stripes started out on 7 shared `SLOT_BANDS`, but the current bank has been
  **hand-tuned**: ids 3, 6, 8, 10–15 use data bands shifted off that grid,
  and ids 0, 2, 4, 5 and 8 use a lower top-anchor start than `TOP_ANCHOR_BAND`. Treat
  `IONP_PATTERNS` itself as the definition.
- **Four ids per design, and an id belongs to a design**: `DESIGN_IDS` maps U1.6 → 0–3,
  U2.5 → 4–7, U4 → 8–11, U8 → 12–15. Within a design the four ids differ in ≥ 2 stripes, so
  one misread stripe can't turn one id into another. U1.6's ids are one-hot (one data
  stripe each): its array has room for no more.
- An id fits the design it was made for and every **longer** one, never a shorter one;
  `ionp.check_design_rules` **raises** `DesignRuleError` rather than stamping a barcode
  that won't decode. `python3 -m electrode_bundle.ionp_patterns` prints the fit matrix.
- Wells within `keepout_radius` (30 µm) of a contact **along its own fiber** are dropped —
  deliberately not a radius in the plane, which at `delta_x` = 24 µm would also clear the
  neighbouring fibers' columns.
- Band heights were sized for ~800 wells, not the 700 floor, because well count is
  quantized: one 5 µm step across 64 columns is ~64 wells.

Check by eye in `all_ionp_patterns_side_by_side.dxf` and with
`python3 -m electrode_bundle.main legend`.

---

## 4. The designs

`design_sets._BASE_DESIGNS` — four uniform-pitch 64-channel arrays:

| name | `sites` span | `fiber_length` | `loop_offset` | `overall_length` | IONP ids |
|---|---|---|---|---|---|
| U1.6 | 1664 | 7000 | 500 | 27 000 | 0–3 |
| U2.5 | 2560 | 10 000 | 250 | 30 000 | 4–7 |
| U4 | 4000 | 10 000 | 500 | 30 000 | 8–11 |
| U8 | 8000 | 12 000 | 500 | 28 000 | 12–15 |

All µm. `DESIGNS` expands each against `DESIGN_IDS` (16 entries); `batch` writes the
barcode-free artefacts once per name and a barcoded DXF per variant.
`_check_variants_unique` rejects two entries with the same `variant_tag`.

---

## 5. Design rules

`ionp.check_design_rules` runs on every IONP build. It enforces `min_n_wells = 700` (the
MRI floor), `max_n_wells = 10_000`, and `min_strip_distance = 300 µm` between stripes, and
**raises** on a violation. Pass `strict=False` for a report dict instead.

`ionp_patterns.validate_pattern` rejects bands outside `[0, 1]`, inverted bands and
overlapping ones.

Geometry asserts inside `build_bundle` (each fails with the number it needed): the hook's
etch wall, the Ref trace clearing the loop hole and staying on the hook, `RefSpec.check`,
the alignment tabs fitting the block edge, every `ref_wrap_*` clearance, and
`solve_lengths` landing within 0.05 µm.

---

## 6. Tests

```bash
python3 -m pytest electrode_bundle/tests -q     # 240 tests, ~15 min
```

| File | Pins |
|---|---|
| `test_electrode_spacing.py` | the staircase: locality (nothing below an edited gap moves) and accumulation. Baselines come from `_base_cfg()`, **not** a bare `BundleConfig()` — the default carries the dense band. Keep it that way |
| `test_spacing.py` | `Uniform` / `Segments` → real electrode positions |
| `test_lengths.py` | `solve_lengths` lands on spec; the ribbon is a fixed connector run |
| `test_hooks.py` | the `drop` contract and the etch wall, per hook |
| `test_electrode_site.py` | round site shapes, tangent joins, contact centres unchanged |
| `test_etch_mask.py` | release moat surrounds everything at the tip; loop and solder-pad openings are in `Etching`; site openings only in `pad_etching`; coating/label placement |
| `test_metal_routing.py` | every channel actually reaches its pad in the drawn gold; teardrop spacing wall |
| `test_pad_assignment.py` | today's channel → pad assignment, and no route crossings |
| `test_bundling.py` | `TwoArcFold` / `NoFold`, `precompensate`; the JSON record; per design: contacts drawn on spec, shoulder staggered by exactly the fold cost, solved lengths undisturbed |
| `test_ionp_id.py` | bank structure (anchors, ≥ 2-stripe distance, `DESIGN_IDS`), every design fits its ids with margin, design-rule raising, keep-out, config defaults, legend, CLI |

---

## 7. Gotchas

1. **`main.py ionp` needs its input DXF to already exist** at
   `<TARGET_SET>/shanks/electrode_bundle_C{NN}.dxf`; it stamps wells onto that file in place.
   `all` and `batch` sidestep this.
2. **Run from the parent of `electrode_bundle/`** with the module form
   `python3 -m electrode_bundle.<name>`. Every module uses relative imports, so running one
   by file path fails with `ImportError: attempted relative import with no known parent
   package` — except `id_legend.py`, which carries a `__package__` bootstrap.
3. **`<TARGET_SET>/shanks/` is disposable** — regenerated from `design_sets.py` +
   `config.py`. Copy a design out to keep it.
4. **Never nest the plain `electrode_bundle_<name>.dxf`** — it has no `IONP` layer. The
   WaferNesting config nests the `<tag>` variants.
5. **`save_dxf` mutates the doc**: the build-only layers are deleted from it, not just from
   the file. Read contact centres before saving (everything in the package does).
6. **`ref_dxf` is optional and off.** Setting `BundleConfig.ref_dxf` drives contact centres
   from a reference DXF instead of the parametric grid. That file is not part of this
   folder; you would have to supply it.
7. **`mapping.build_mapping` asserts no recording channel lands on flex 65/66.** That is
   correct: the Ref is not in the channel mapping. It reports which REF/GND pad the Ref
   reaches as `ref_gnd_connected`.
8. **`max_theta_deg` drives drawn geometry** (the shoulder stagger), not just the reported
   bundled positions. Calibrate it before trusting a wafer's fiber lengths.
9. **Units are µm** throughout.

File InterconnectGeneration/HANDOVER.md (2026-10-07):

# InterconnectGeneration — handover

Generates the MEA1K interconnect DXFs. Stage 01 builds the chip-side part (pad grid,
per-column Metal1 routing, vias, polyimide); stage 02 routes its wire band into a Molex
227044 connector. Output is the routed DXF in µm, which `WaferNesting/` places on the wafer
(§1.1).

Designs, with defaults matching the fabricated wafer, which ships as
`reference/WaferWith12_ALLNEW.gds` (byte-identical to
`../MEA1K_wafer4_12x_8x_8x_breakoutboards_Rev2.gds`, which `WaferNesting/config_rev2.py`
reads):
**12-block** `56_15` (768 wires, two metal layers), **8-block** `51_35` (512 wires, one
layer), and the **dummy** `61_10`, a 12-block pad grid whose wire band is shorted by a cap
(etch/release test structure, GDS output). The wafer's other two variants, 8-block `71_15`
and dummy `35_36`, are the same configs with a few values overridden (§4.4).

**Wafer revisions.** Rev2 is the fabricated wafer; its designs are in `designs/`. **Rev3**
changes only the pad stack (§4.5): the final PI etch becomes via-sized circles around each
pad's perimeter, and a new Metal3 layer repeats the pad squares. Its designs are in
`designs/rev3/`, its wafer is built at Rev2's exact placements (§1.1). `build_designs.py`
builds all five designs of either revision.
`old_interconnect/` holds the two old-interconnect routers, which append connector routing to a
fixed asset (`assets/mea1k_interconnect_only.dxf`) and cannot be re-parameterised.

Inputs are in `assets/`, outputs go to `designs/` (created on first run). `designs/` ships with
the fabricated (Rev2) set: the stage-01 and stage-02 files of all five wafer designs, generated
by `build_designs.py --rev 2` and proven against the wafer cell by cell (XOR = 0, by
`WaferNesting/01c_extract_exact_placements.py`, §1.1). Rerunning them overwrites
these files with identical geometry. Paths are derived from file locations
(`HERE/ASSETS/DESIGNS` in `lib/active.py`; duplicated in `00_preflight.py` and `_HERE` in
each `old_interconnect/` script).

## 1. Running

```bash
pip install ezdxf shapely numpy gdstk matplotlib   # gdstk: dummy; matplotlib: old_interconnect/
# (here: the base conda python, /opt/anaconda3/bin/python3 -- the `dxf` env lacks gdstk)

python3 build_designs.py --rev 3         # ALL five designs of a revision, stage 01 + 02 (~1 min)
python3 build_designs.py --rev 2 --out-dir /tmp/rev2   # Rev2 settings: regression vs designs/

# or one stage of one design, with the configs' defaults (the default variant of each family):
python3 00_preflight.py                  # env + pad-grid constraints (§4.2), no run
python3 01_generate_12block.py           # -> designs/new_interconnect_circular_12Block_56_15.dxf
python3 02_route_12block.py              # -> designs/new_interconnect_with_connector_chamfered_12Block_56_15.dxf
python3 01_generate_8block.py            # -> designs/new_interconnect_circular_8block_51_35.dxf
python3 02_route_8block.py               # -> designs/new_interconnect_with_connector_8blocks_chamfered_1layer_51_35.dxf
python3 01_generate_12block.py --config dummy    # -> designs/new_interconnect_circular_dummy_61_10.dxf
python3 02_make_dummy.py                 # -> designs/dummy_new_interconnect_circular_dummy_61_10_padrows.gds
python3 03_inspect.py [file.dxf]         # per-layer entity/vertex census + bbox

python3 old_interconnect/02_route_old_12block.py         # minutes; no CLI; ~99 MB final + debug
python3 old_interconnect/02_route_old_8block_doubled.py
```

- `build_designs.py` is the way to build a wafer's designs. Each design is its config plus
  the overrides in `VARIANTS` (§4.4); each revision adds those in `REVISIONS` (§4.5). Every
  stage runs in its own process with the overrides applied in memory, so no config is edited
  and nothing leaks between designs. Output: `designs/` (Rev2, same names as shipped) or
  `designs/rev3/` (`*_rev3.*`), logs in `<out-dir>/logs/`. It **fails** (exit 1) when a stage
  errors or a router prints `crossings`/`pad_hits` ≠ 0 or a `FAIL` line — the routers
  themselves only print those.
- Pad parameters are changed in the config file. Pad size, gap and via position depend on
  each other and are edited together (§4.4).
- Options: generators `--out` (plus `--config 12block|dummy` on the 12-block one); routers and
  `02_make_dummy.py` `--in --out`. Defaults come from the config, and each generator's
  default output is its stage 02's default input. Bare filenames resolve to `designs/`,
  absolute paths are used as given.
- The routers take no pad parameters; they measure the band off the input DXF.
- Stage 01 ~1 s, stage 02 10–20 s. Each run writes exactly one DXF (the dummy: one GDS).
- A good stage-02 run prints `crossings=0, pad_hits=0`, `phase-2 fan … : OK`, the teardrop
  tally (§5), and the layer split `Metal1(even)=384, Metal2(odd)=384` (12-block) or
  `Metal1=512, Metal2=0 (single layer)` (8-block).

### 1.1 WaferNesting

`WaferNesting/` lives inside this folder (`ROOT` = `InterconnectGeneration/`, `DESIGN_DIR` =
`designs/`). It has two paths, each driven by one config:

**Reproduce the fabricated wafer** — `config_rev2.py`, target
`../MEA1K_wafer4_12x_8x_8x_breakoutboards_Rev2.gds` (byte-identical to
`reference/WaferWith12_ALLNEW.gds`):

```bash
export WAFERNEST_CONFIG=config_rev2
KL=/Applications/KLayout/klayout.app/Contents/MacOS/klayout
$KL -b -r WaferNesting/01c_extract_exact_placements.py   # wafer -> runs/wafer4_rev2/placements.json
$KL -b -r WaferNesting/01d_rebuild_wafer.py              # -> runs/wafer4_rev2/wafer_wafer4_rev2.gds, then checks it
```

01c proves every part of the wafer comes from a source (each cell XOR = 0 against its file
in `designs/`, TOP's marks against the wafer template) and records all 38 placements
exactly — the 12 connectors and the 26 dummies, which were placed by hand into the gaps and
are never nested. 01d builds the wafer from that and ends with `GEOMETRY IDENTICAL`.
It is not byte-identical (GDS timestamps, writer record order); placement angles agree to
~1e-13 deg, i.e. KLayout's sine/cosine round trip, below anything the 1 nm grid can hold.
To put revised content at the same placements, point the cell's entry in `SOURCES`
(`config_rev2.py`) at the new file and run 01d alone. 01c also reports the wafer's one
duplicate placement: two `dummy_61_10_NEW` at (42.779, −9.325) mm, 31°.

**Build the Rev3 wafer** — `config_rev3.py`: the Rev2 placements, every cell swapped for its
Rev3 design, plus the template's layer-8 alignment marks for Metal3:

```bash
python3 build_designs.py --rev 3                                    # designs/rev3/
WAFERNEST_CONFIG=config_rev2 $KL -b -r WaferNesting/01c_extract_exact_placements.py
WAFERNEST_CONFIG=config_rev3 $KL -b -r WaferNesting/01d_rebuild_wafer.py   # -> runs/wafer4_rev3/
WAFERNEST_CONFIG=config_rev3 $KL -b -r WaferNesting/01e_overlay_wafers.py  # Rev2 + Rev3 in one GDS
```

01d checks the Rev3 wafer against Rev2 and passes only if layers 3 and 8 are the only ones
that changed, each change inside the Metal2 pads (apart from TOP's new marks). 01e writes
both wafers into one GDS (Rev2 on datatype 0, Rev3 on 1, their XOR on 2) with a `.lyp`
naming the layers, for checking alignment by eye.

**Nest a new wafer** — `config.py`, the three routed connector DXFs, 4 copies each, seeded
from `WaferNesting/reference_run_2026-07/`: `00_check_setup.py`, `01_extract_footprints.py`,
`02_nest.py`, then `03_export_wafer.py` / `04_verify_wafer.py` in KLayout. It nests the
connectors only — no dummies — and its `LAYER_MAP` is the pre-renumbering one (see below),
so its GDS does not land on the fabricated wafer's layers.

The wafer's sources in `designs/`: the three routed connector DXFs and the two
`dummy_*_padrows.gds`. The connector cells sit −90 µm in y from their DXFs; 01c measures
that. WaferNesting reads only `LWPOLYLINE`/`HATCH` from a DXF, which is all the new
interconnect emits.

**Wafer layer numbers were changed by hand.** In `reference/WaferWith12_ALLNEW.gds` the GDS
layers were renumbered manually to match the negative-etching markers, so the numbering this
folder's scripts write is not the wafer's. For the dummy the mapping is 1 → 3 and 3 → 7
(5 and 6 unchanged): with it, both `*_padrows.gds` files in `designs/` are polygon-for-polygon
identical to the wafer's `dummy_61_10_NEW` / `dummy_35_36_NEW` cells. Check the numbering
against the reference wafer before placing anything on a new one.

The fabricated numbering, as `config_rev2.py` / `config_rev3.py` write it:

| Wafer layer | DXF layers | Dummy GDS layer | Alignment mark (template) |
|---|---|---|---|
| 7 | Metal1 | 3 | reference marks, all slots |
| 3 | Polyimide_Negative, EtchingPad (Rev3 etch circles are on Polyimide_Negative) | 1 | inverted, slot 4 |
| 5 | Etching, Via | 5 | inverted, slot 1 |
| 6 | Metal2 | 6 | small, slot 5 |
| 8 | Metal3 (Rev3 only) | 8 | small, slot 3 (Rev3 only) |
| 10 | — | — | wafer outline |

The mark row sits at y = 0, x ≈ ±41…±46 mm. Layer 7 carries a reference vernier in each of
five slots (slot 1 outermost, x ≈ ∓44.0 mm, to slot 5, x ≈ ∓41.2 mm); every other layer
puts its own mark in one slot and repeats the coarse marks at x ≈ ∓45.9 and ∓44.7 mm. The
template's layer 1 holds one more small mark (slot 2), still unused.

## 2. Code layout

```
config_12block.py, config_8block.py   all design knobs of one design, in physical order:
                                        1 pad grid (GEN_*), 2 connector, 3 Phase 1,
                                        4 Phase 2, 5 teardrops, 6 polyimide, 7 derived
config_dummy.py                       dummy: 1 pad grid (GEN_*), 2 cap (DUMMY), layer map
config_common.py                      derived values shared by both designs
build_designs.py                      builds all five designs of a revision; VARIANTS (§4.4)
                                        and REVISIONS (§4.5) as data
00_preflight.py                       checks §4.2 against the configs
01_generate_{12block,8block}.py       stage 01 (the 12-block one also builds the dummy grid)
02_route_{12block,8block}.py          stage 02: design-specific functions + main()
02_make_dummy.py                      stage 02 for the dummy: band cap + DXF -> GDS
03_inspect.py                         layer census
lib/active.py                         loads the selected design's config
lib/constants.py                      layer names, sampling resolutions
lib/teardrop.py                       teardrops, pad approach, angled entry, clearance clamp
lib/connector.py                      connector pads (CSV) and routing ranks
lib/board.py                          polyimide: board outline, neck / flare, bulbs
lib/phase1.py, lib/fanmath.py         band -> hand-off transition; eased fan profile + gap check
lib/geometry.py, lib/checks.py        helpers; crossings / pad_hits
lib/generate_helpers.py               stage-01 helpers
old_interconnect/                     old-interconnect routers, standalone
WaferNesting/                         wafer layout: nest a new wafer, or reproduce the
                                        fabricated one exactly (§1.1, WaferNesting/HANDOVER.md)
electrode_bundle_U4C08.dxf            reference for the teardrop profile (§5); not read
reference/WaferWith12_ALLNEW.gds      the fabricated wafer the defaults match; not read
```

**Config mechanism.** `lib` functions read knobs as module globals (`PADR`,
`TEARDROP_CLEAR`, …). Each router calls `lib.active.select(design, in, out)` before
importing from `lib`; `select` loads `config_<design>.py`, `lib/constants.py` and the paths
into `lib.active`, which every `lib` module star-imports. Importing `lib` before `select`
raises. One design per process — the connector-pad cache in `lib/connector.py` is
module-level, and default arguments bind config values at import.

**Router split.** `lib/` holds everything common to both designs. The routers keep only what
differs (a banner under the imports lists it):

| | 12-block | 8-block |
|---|---|---|
| Phase 1 | fans the band out to `FAN_TARGET_PITCH`, lifts odd wires to Metal2 through vias (layer `Via`) | keeps native band x, stays on Metal1; drops the 16 pair-short ties at the band |
| Connector | 8 blocks from the CSV + 4 synthesised (`N_NEW_BLOCKS_PER_COLUMN`) | the 8 CSV blocks |
| In-block routing | `route_single_*` | `route_blue_terminal*`, `route_green_single*` |
| Trace width | widens below the fan (`taper_widths_along_path`) | narrows 3.5 → 2 µm in the neck, above the fan-in |
| Polyimide | neck flares over the fan (`fanout_*`) | no flare |

Derived values (config section 7, `config_common.py`) keep the original expressions, so
float results are bit-identical to the pre-refactor code. Don't reorder that arithmetic.

## 3. New vs old interconnect

| | stage 01 | stage 02 |
|---|---|---|
| new (12/8-block) | pad grid + routing → `*_circular_*.dxf` | fan-in, optional via split, connector routing |
| old | none (opaque 31 MB asset derived from the wafer GDS) | appends connector routing |

## 4. Parameters

### 4.1 Primary knobs

Stage 01, `GEN_CONFIG` (config section 1):

| Knob | 12-block | 8-block | |
|---|---|---|---|
| `pad_side` | 58 µm | 53 µm | metal pad (Metal2), the bigger square; pitch = `pad_side + gap` |
| `pad_side_extra` | 56 µm | 51 µm | Rev2 etch opening (EtchingPad), the smaller square on the same centre; 1 µm metal rim. Only used with `pad_etch="square"` |
| `pad_etch` | `"vias"` | `"vias"` | final PI etch: `"square"` (Rev2) or perimeter circles (Rev3), §4.5 |
| `metal3` | `True` | `True` | also draw the pad squares on Metal3 (Rev3), §4.5 |
| `gap` | 13 µm | 33 µm | metal-to-metal gap between pads |
| `n_rows` × `n_cols` | 15 × 53 | 12 × 44 | both at the fit limit (§4.2) |
| `n_shorts_left/right` | — | 8 / 8 | each folds one pad into a neighbour's exit |

Stage 02 (config sections 2 and 5):

| Knob | 12-block | 8-block | |
|---|---|---|---|
| `TOTAL_WIRES` | 768 | 512 | connector capacity, 64 × blocks |
| `PADR` / `CONN_PAD_R` | 0.105 / 0.095 mm | same | metal pad + collision radius / `Polyimide_Negative` circle |
| `CONNECTOR_TW` / `GAP` | 3.5 / 0.5 µm | 2.0 / 3.0 µm | 12-block lanes alternate layers, so its same-layer gap is 2 × pitch − TW |
| `TEARDROP_FILLET_R_VERTICAL` / `_ANGLED` | 0.275 / 0.10 mm | same | §5 |
| `TEARDROP_CLEAR` | 20 µm | same | §5 |
| `PAD_APPROACH_TW_*` / `_LEN_*` | 30 µm / `None` (auto) | same | trace width at the pad = tear width |

The remaining knobs are tuned: Phase-1 fan and via geometry, `FAN2_*`, `FAN_LEN_SLACK`,
`CONN_TOP_BELOW_VIA_MM`, `ANGLED_ENTRY_*`, `CHAMFER_*`, board and bulb geometry, and stage 01's
`GEN_ROUTING` (wire/via geometry, tuned against fabrication limits). Layer names, sampling
resolutions, tolerances and the fixed stage-01 entries (layers, via shape) are in
`lib/constants.py`; each config merges the latter into its `GEN_*` dicts.

### 4.2 Constraints between stages

- **Wire count:** emitted wires = `TOTAL_WIRES`. 8-block: `n_rows·n_cols − shorts` =
  528 − 16. 12-block: `Σ_cols (n_rows − row_start(col))` = 795 − 27; the bottom pad is
  dropped on columns `0..n_cols//2`.
- **Fit limit:** a column's lanes must fit in one pad pitch,
  `max_rows = (pitch − w − g) // (w + g) + 1` with `w`, `g` from `GEN_ROUTING`.
- **Via staircase:** `via_offset_x + (n_rows − 1)·via_pitch + via_r ≤ pad_side`.

`00_preflight.py [--design 12block|8block|dummy]` evaluates all three from the configs
without generating anything, and warns if `via_offset_y` no longer puts the via in the pad's
top-left corner (`pad_side/2 − via_offset_x`).

### 4.3 Design names

Names describe the **etch openings**, not the metal:
`<pad_side_extra>_<gap + pad_side − pad_side_extra>` = opening side and the gap between
neighbouring openings. 12-block 58/56/13 → `56_15`;
8-block 53/51/33 → `51_35`; 8-block 73/71/13 → `71_15`; dummy 63/61/8 → `61_10`;
dummy 37/35/34 → `35_36`.

### 4.4 Wafer variants

The configs default to one variant per family. The wafer's other two differ only in the pad
grid, the via position (`via_offset_y` = `pad_side/2 − 2.75`, i.e. the via sits in the pad's
top-left corner) and the file names:

| Variant | `pad_side` | `pad_side_extra` | `gap` | `via_offset_y` | Pitch | `N_RIGHT_BULBS` |
|---|---|---|---|---|---|---|
| 8-block `51_35` (default) | 53 | 51 | 33 | 23.75 | 86 | 2 |
| 8-block `71_15` | 73 | 71 | 13 | 33.75 | 86 | 1 |
| dummy `61_10` (default) | 63 | 61 | 8 | 28.75 | 71 | — |
| dummy `35_36` | 37 | 35 | 34 | 15.75 | 71 | — |

The two 8-block variants also differ in the extraction-tab bulbs on the neck's right wall:
the fabricated `51_35` carries two, `71_15` one. Until 2026-10-07 the config had 1 for both,
so the shipped `51_35` DXF was missing a bulb against the wafer (found by 01c, §1.1).

This table is `VARIANTS` in `build_designs.py`: each variant is its config plus those
overrides, applied in memory, so the configs keep their defaults and nothing has to be edited
and reverted. `python3 build_designs.py --rev 2 --out-dir <dir>` rebuilds all five with Rev2
settings, geometry-identical to the files shipped in `designs/` (checked 2026-10-07), and
those match the wafer (proven by `WaferNesting/01c_extract_exact_placements.py`: XOR = 0 per
cell). The `71_15` vias sit 33.75 µm from their pad centres in x and y, as in the wafer's
`CONN_SMALL_71_15_NEW` cell, and the dummy GDS files equal the wafer's dummy cells after the
layer remap (§1.1). Forgetting `via_offset_y` leaves the via off its corner: 23.75 on
`71_15` puts every via 10 µm low. Preflight warns about exactly that.

### 4.5 Pad stack per revision

`REVISIONS` in `build_designs.py` sets the pad-stack knobs of `GEN_CONFIG` for every design:

| | Rev2 (fabricated) | Rev3 |
|---|---|---|
| `pad_etch` | `"square"`: one `pad_side_extra` square per pad on EtchingPad | `"vias"`: circles around the pad perimeter on Polyimide_Negative |
| `metal3` | `False` | `True`: the pad squares again on Metal3, no wires |
| output | `designs/` | `designs/rev3/*_rev3.*` |

**Rev3 etch vias** (`01_generate_*.py`, `perimeter_via_centres` / `vias_per_side_for` in
`lib/generate_helpers.py`). Each circle has the routing via's diameter (5 µm) and its inset
(centre 2.75 µm from the pad edge, 0.25 µm edge to edge), so the corner circles line up with
the routing via. Every side carries the same number, corners included; the corner over the
routing via (top-left) is left out. The count is the one whose spacing lies in
`etch_via_spacing` = (15, 20) µm (`lib/constants.py`, one range for all designs) and is
nearest its middle:

| Design | Pad (Metal2 = Metal3) | Per side | Spacing (centres) | Gap (edges) | Circles per pad |
|---|---|---|---|---|---|
| 12-block | 58 µm | 4 | 17.50 µm | 12.50 µm | 11 |
| 8-block `51_35` | 53 µm | 4 | 15.83 µm | 10.83 µm | 11 |
| 8-block `71_15` | 73 µm | 5 | 16.88 µm | 11.88 µm | 15 |
| dummy `61_10` | 63 µm | 4 | 19.17 µm | 14.17 µm | 11 |
| dummy `35_36` | 37 µm | 3 | 15.75 µm | 10.75 µm | 7 |

Spacing = (`pad_side` − 5.5) / (per side − 1); circles per pad = 4 × (per side − 1) − 1.
The generator stops if no count fits the range, if circles would overlap, or if a pad does
not have exactly one perimeter position on its routing via. The routers pass Metal3 and the
circles through untouched (they read Polyimide_Negative only as HATCH); the dummy picks the
circles up through `"Polyimide_Negative": (1, 0)` in `DUMMY_LAYER_MAP`, which reads its
LWPOLYLINEs only, not the band hatch. Against Rev2, every Rev3 design differs on exactly these
layers and nothing else.

The design names (§4.3) still describe the Rev2 etch squares.

## 5. Teardrops and angled entry (`lib/teardrop.py`)

Each connector pad is a teardrop matching the mating electrode bundle
(`electrode_bundle_U4C08.dxf`: pad r 110 µm, trace 10 µm, fillet r 275 µm). The outline is
the pad circle plus two concave fillet arcs, tangent externally to the pad and to the trace
edges; `teardrop_ring` reproduces the reference to 0.09 µm. The tip distance is derived:

```
L = sqrt((r + F)^2 - (w/2 + F)^2)     r = PADR, F = fillet radius, w = PAD_APPROACH_TW_*
```

- **Width coupling.** `teardrop_tip_width()` returns the same `PAD_APPROACH_TW_*` that
  `widen_pad_approach()` applies to the trace, so the tear and the trace share one width knob.
- **Hold extension.** `PAD_APPROACH_HOLD_*` is raised per pad to `max(hold, L / ramp_len)`,
  so the trace is at full width over the whole tear. Tip width and trace width agree to
  ≤ 1 µm on the emitted DXF.
- **Clearance clamp.** Each tear is shrunk by bisection on `L` until the metal it adds holds
  `TEARDROP_CLEAR` from foreign stroked copper (the emitted polygons, not centrelines). It is
  also capped at the trace's last straight run. With `TEARDROP_CLEAR_FLOOR_FROM_PAD`, a pad
  whose bare clearance is already below `TEARDROP_CLEAR` is held to that existing gap
  instead of being denied a tear (12-block: 192 such pads, tightest 9.2 µm; 8-block: 144,
  tightest 3.5 µm).
- **Angled fillet.** The angled rows use 0.10 instead of 0.275 because their entry angle
  drifts across a row (135° → 120°), and a 0.275 fillet (2.6 × `PADR`) flares far beyond a
  30 µm wire. 0.10 keeps the flare proportionate and the row uniform.

Result: 12-block 708 full / 60 shrunk / 0 plain; 8-block 468 / 44 / 0.

**Angled entry** (`ANGLED_ENTRY_*`). On the flanked rows — left column rows 1, 3, right
column rows 2, 4 (the right blocks are rotated 180°) — the final approach is one straight
segment from the feed lane into the pad. Each route tries 45° first and steepens only as far
as needed to clear every foreign pad and trace, so `crossings = 0, pad_hits = 0` holds by
construction. About a third reach 45° (12-block 120/384, 8-block 80/256); the rest are
steeper, medians 52–63°, max 68°. Four 8-block entries on L row 3 stay perpendicular.

## 6. Common problems

**Stage 02 raises in `extract_band_endpoints` after parsing the whole input.**
The wire count (§4.2) doesn't match `TOTAL_WIRES`. Changing `n_rows`/`n_cols` without
rebalancing the shorts (8-block) or `row_start` (12-block) causes it. `00_preflight.py`
catches it up front.

**Adding a row makes the column bundles overlap.** Both designs are at the fit limit
(15 ≤ 15, 12 ≤ 12); one more row needs a larger `gap` or `pad_side`.

**The 8-block Phase-2 fan flips to FAIL.** Its same-layer gap is +2.999 µm against a
3.00 µm target (`FAN_CHECK_TOL_UM` covers the discretisation); the 12-block has +3.458
against 2.50. Any change to `FAN2_*`, `FAN_LEN_SLACK`, `CONNECTOR_TW`, `GAP` or the wire
count can break it, and the failure is real — widen the fan.

**Tear and trace widths don't match.** `PAD_APPROACH_LEN_* = 0` (any falsy value) skips the
widening (`if _tw is not None and _rl:`), while the tear is still built at
`PAD_APPROACH_TW_*`. Keep it `None`.

**Editing `angled_pad_entry`.** The diagonal has to be tested against foreign *traces*, not
just pads: the sweep crosses the unmodified feed lanes of rows 2/4. Testing pads only gave
157 crossings; indexing every route's full geometry gives 0.

**Spacing violations the checks don't report.** `crossings`/`pad_hits` are centreline-only.
Tears are drawn after them and are invisible to them. Edge-to-edge copper spacing is checked
only by the teardrop clamp. There is no DRC and no test suite. The closest thing to a
regression test: `python3 build_designs.py --rev 2` (rewrites `designs/`) and then
`WaferNesting/01c_extract_exact_placements.py` with `WAFERNEST_CONFIG=config_rev2` — it XORs
every design against the fabricated wafer and fails on any change. For changes that are *meant* to alter geometry, compare DXFs before and
after (KLayout XOR, or the `03_inspect.py` census).

**Two runs never match byte for byte.** ezdxf stamps `$TDCREATE`/`$TDUPDATE`. Compare
geometry.

**ezdxf can't read a DXF back after KLayout saved it.** KLayout writes AC1006, and its
LWPOLYLINE mode produces files ezdxf can't parse. Go DXF → GDS one way only.

**WaferNesting under-covers old-interconnect designs.** Both old-interconnect outputs contain 4957 `POLYLINE`
entities inherited from `mea1k_interconnect_only.dxf` (`Metal` 1898, `Metal2` 1813,
`L3D0_etching2` 844, `L1D0_etching1` 402); WaferNesting reads only `LWPOLYLINE`/`HATCH`.
Convert before nesting an old-interconnect design. The new interconnect emits only `LWPOLYLINE`/`HATCH`.

**The old-interconnect 8-block debug DXF differs between runs.** Pads are drawn by iterating a `set`
of layer names, so their order depends on the hash seed. Geometry is unchanged and
`_final.dxf` is unaffected; `PYTHONHASHSEED=0` makes it repeatable.

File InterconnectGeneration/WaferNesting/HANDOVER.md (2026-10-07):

# WaferNesting (interconnect) — handover

Puts MEA1K interconnect designs onto a 100 mm wafer and writes the combined GDS. It has
**two paths**, and they answer different questions:

| Path | Question | Stages | Config |
|---|---|---|---|
| **nest** | "arrange these N pieces legally on a new wafer" | `00` → `01` → `02` → `03` → `04` | `config.py` |
| **reproduce** | "rebuild this existing wafer, exactly, from its sources" | `01c` → `01d` | `config_rev2.py` |
| **revise** | "the same wafer, with revised designs at the same placements" | `01c` → `01d` → `01e` | `config_rev3.py` |

The reproduce path is what the fabricated wafer is maintained with: the Rev2 wafer is
rebuilt from `../designs/` geometry-identically (§4.2). New wafer revisions that keep the
layout start there, not from a fresh nest: Rev3 (§4.3) is Rev2's placements with every cell
swapped for its Rev3 design, checked against Rev2 layer by layer.

Every stage is driven by one config file, chosen with `WAFERNEST_CONFIG`; the stage scripts
hold no paths, clearances or layer numbers of their own. The wafer template and alignment
marks ship inside this folder.

> This is one of **two** WaferNesting forks. The other, in
> `../../generative_probe_design/WaferNesting/`, nests electrode probes: it has a
> count-maximising skyline nester, dark-field mark inversion and a wafer map, but no
> reproduce path. They share 00/01/footprint code almost line for line. §6.3.

---

## 0. Where it sits

```
programmaticMaskDesign/
  MEA1K_wafer4_12x_8x_8x_breakoutboards_Rev2.gds   <- the fabricated wafer (reproduce target)
  InterconnectGeneration/                          <- ROOT for every config here
    designs/                                       <- DESIGN_DIR: the routed DXFs + dummy GDSs
    WaferNesting/                                  <- this folder
      00_check_setup.py … 04_verify_wafer.py       <- nest path
      01c_extract_exact_placements.py              <- reproduce path
      01d_rebuild_wafer.py
      01e_overlay_wafers.py                        <- old + new wafer in one GDS
      exact_io.py                                  <- shared by 01c and 01d
      config.py, config_rev2.py, config_rev3.py, config_common.py
      config_electrode_bundle.py                   <- legacy, see §6.4
      footprint_extract.py
      new_wafer_actually.GDS, marks_union.wkt      <- wafer template + marks
      reference_run_2026-07/                       <- the 2026-07 nest seed. Do not edit
      runs/<RUN_TAG>/                              <- all output
```

Run from `InterconnectGeneration/`. Paths are anchored to the files themselves, so the
working directory does not actually matter; that is just the one the commands below use.

## 1. Quickstart

```bash
pip install ezdxf shapely numpy matplotlib        # stages 00-02 (conda env `dxf`)
KL=/Applications/KLayout/klayout.app/Contents/MacOS/klayout   # stages 01c, 01d, 03, 04
```

KLayout's own Python runs the GDS stages (`$KL -b -r <script>`); the `klayout` pip module
is not used. Those scripts and every config they import must stay pure standard library +
`pya` (gotcha 8).

### 1.1 Reproduce the fabricated wafer

```bash
export WAFERNEST_CONFIG=config_rev2
$KL -b -r WaferNesting/01c_extract_exact_placements.py   # ~10 s
$KL -b -r WaferNesting/01d_rebuild_wafer.py              # ~2 min, mostly the final check
```

01d must end with `GEOMETRY IDENTICAL`. To put revised content at the same placements,
use a revision config (§1.2), not an edited `config_rev2.py`.

### 1.2 Build the Rev3 wafer

```bash
python3 build_designs.py --rev 3                                     # ../designs/rev3/
WAFERNEST_CONFIG=config_rev2 $KL -b -r WaferNesting/01c_extract_exact_placements.py
WAFERNEST_CONFIG=config_rev3 $KL -b -r WaferNesting/01d_rebuild_wafer.py    # ~2 min
WAFERNEST_CONFIG=config_rev3 $KL -b -r WaferNesting/01e_overlay_wafers.py   # ~4 min
```

01d must end with `IDENTICAL to MEA1K_wafer4_…_Rev2.gds except the expected changes on
3/0, 8/0`. 01e writes `runs/wafer4_rev3/overlay_wafer4_rev3.gds` + `.lyp`: Rev2 on
datatype 0, Rev3 on 1, their flattened XOR on 2 (open with `klayout <gds> -l <lyp>`).

### 1.3 Nest a new wafer

```bash
export WAFERNEST_CONFIG=config        # the default when unset
python3 WaferNesting/00_check_setup.py          # resolves every path, changes nothing
python3 WaferNesting/01_extract_footprints.py
python3 WaferNesting/02_nest.py                 # ~80 s from the seed
$KL -b -r WaferNesting/03_export_wafer.py
$KL -b -r WaferNesting/04_verify_wafer.py       # must end ALL CHECKS PASSED
```

`config.py` nests the three connector designs only — no dummies — and writes the
pre-renumbering layer numbers (§6.1). Read §6 before fabricating anything from it.

### 1.4 Stages and outputs

| Stage | Does | Runs in |
|---|---|---|
| `00_check_setup.py` | verifies packages, KLayout and every input path; names the setting to fix | python3 |
| `01_extract_footprints.py` | design DXF → silhouette + centroid offset (+ per-kind envelopes) | python3 |
| `02_nest.py` | silhouettes → poses `[kind, angle, x, y]`, simulated annealing to feasibility | python3 |
| `03_export_wafer.py` | poses + **original DXFs** → wafer GDS | KLayout |
| `04_verify_wafer.py` | counts, per-layer shape totals, max radius vs the sources | KLayout |
| `01c_extract_exact_placements.py` | existing wafer → `placements.json`, every part proven against its source | KLayout |
| `01d_rebuild_wafer.py` | `placements.json` + sources + template → wafer GDS, checked against the original | KLayout |
| `01e_overlay_wafers.py` | the original + the rebuilt wafer → one GDS on datatypes 0 / 1, XOR on 2, + `.lyp` | KLayout |

All output goes to `runs/<RUN_TAG>/`:

| File | From | What |
|---|---|---|
| `footprint_<key>.json` + `_offset.json` | 01 | silhouette (centred) and the centroid to undo it |
| `envelope_<kind>.json` | 01 | union envelope, only for kinds with > 1 design |
| `footprints_overlay.png` | 01 | visual check of every silhouette |
| `poses.json`, `nest_preview.png` | 02 | the nest |
| `wafer_<RUN_TAG>.gds` | 03 / 01d | the wafer |
| `placements.json` | 01c | target identity, template layers, per-cell source + offset + XOR proof, every placement |
| `overlay_<RUN_TAG>.gds` + `.lyp` | 01e | old and new wafer overlaid, with their XOR |

Runs present today: `interconnect_4x3` (config.py, 2026-10-07), `wafer4_rev2`
(config_rev2), `wafer4_rev3` (config_rev3), and two older ones, `example_4x3` and `electrode_bundle_IONP_id11`, kept
for comparison. Stage 03 refuses to overwrite its GDS; 01d overwrites its own (it is fully
determined by `placements.json` and the sources).

---

## 2. Architecture

### 2.1 Nest path — nest a proxy, place the original

```
  design DXFs
       │
  01 ──┴─► footprint polygon + centroid offset       a COLLISION PROXY, nothing else
  02 ──┴─► poses: [kind, angle, x, y] x N            simulated annealing to feasibility
  03 ──┴─► FULL geometry from the original DXFs,     layer-remapped, placed at those poses
  04 ──┴─► independent verification                  pass / fail
```

The footprint never appears in the output. Placement is `t_place * t_rot * t_center`:
undo stage 01's centring with that design's own offset, rotate, translate.

### 2.2 Reproduce path — prove, then rebuild

```
  existing wafer GDS ──► 01c ──► placements.json ──► 01d ──► wafer GDS ──► check vs original
        + SOURCES          │   per cell: source, offset, XOR proof        (same 01d run)
        + template         │   TOP: which template layers survive
                           └── every placement: integer-dbu position, angle, mirror, mag
```

Both stages load sources through `exact_io.py`, so the stage that proves a source
reproduces a cell and the stage that builds the cell from it cannot disagree about what
"the source, layer-mapped" means.

| Module | Role |
|---|---|
| `config.py` | nest path: the 3 connector DXFs, counts, clearances, seed, `LAYER_MAP` |
| `config_rev2.py` | reproduce path: target wafer, template, one `SOURCES` entry per wafer cell, the fabricated layer maps |
| `config_rev3.py` | revise path: Rev2's `placements.json`, Rev3 `SOURCES`, `EXTRA_TOP_LAYERS`, `EXPECTED_CHANGED_LAYERS`, `CHANGES_WITHIN` |
| `config_common.py` | derived settings for the nest configs (paths, `DESIGNS` helpers) |
| `footprint_extract.py` | DXF → silhouette, for stage 01 |
| `exact_io.py` | source → polygons, template → polygons, GDS header, transform records |
| `new_wafer_actually.GDS` | wafer outline + alignment marks (third mark cluster at x ≈ +96 mm is off-wafer) |
| `marks_union.wkt` | the marks as a shapely geometry, mm — the nester's keep-out |
| `reference_run_2026-07/` | footprints and poses of the 2026-07 nest; `config.py`'s seed. **Do not edit** |

---

## 3. The ideas worth understanding

### 3.1 The count is an input; there is no density objective

`count` in `DESIGNS` **is** N. Stage 02 answers *"can these N pieces be placed legally?"* —
never *"how many fit?"* The cost is

```
4*(area outside usable) + 4*(area on marks) + 1*(pairwise overlap area)
```

and every term is zero for *any* legal layout, so the solver stops at the first zero it
reaches. That is right for the connectors — N is fixed by what is needed, the pieces are
bottle-shaped at ~70 % fill, and feasibility is the hard part. It is wrong when you want a
maximum count: measured on a 3.1 × 27 mm probe strip, a plain column nest seats 66 where
this solver, asked for 24, placed exactly 24 in a loose layout. It also scales badly (full
N × N overlap matrix; painful past ~40 pieces). For count-maximising, use the other fork's
`nest_tiler.py`.

### 3.2 What the footprint is, and why it must not under-cover

The silhouette is the union of **every** layer, then its outer shape. `extract()`:

1. read every LWPOLYLINE and HATCH on every layer, µm → mm;
2. `unary_union` of all of it;
3. `buffer(+CLOSE_GAP).buffer(-CLOSE_GAP)` — closes hairline splits;
4. **drop interior holes** — a design with a hole through it nests as solid;
5. if still disjoint, **keep the largest part only** (stage 01 warns);
6. `simplify(SIMPLIFY)`, then centre on the centroid.

Union of every layer means the footprint can only **over**-cover, which is wasteful and
harmless. Under-covering is the dangerous direction: the nester's `GAP` is the *whole*
clearance mechanism and nothing downstream re-checks the true shapes against each other, so
a footprint smaller than the body yields a "feasible" nest whose pieces collide on the mask.

### 3.3 The clearances are measurements, not preferences

`EDGE_EXCL 3.0` / `GAP 0.05` / `MARK_BUF 0.7` are what the fabricated 2026-07 nest honours
(edge 2.993 mm, inter-piece 0.000 mm, marks 0.701 mm measured against its own footprints).
Older scripts used `GAP 0.3` / `MARK_BUF 1.0`, which no real layout ever achieved: seeded at
those values the search plateaus around 0.35 mm² residual and looks exactly like a slow
annealer. If a run will not converge, check the clearances before adding iterations —
stage 02 prints the seed cost first.

### 3.4 Reproduction is proven, not assumed

01c does not trust the config. For each wafer cell it loads the configured source, maps its
layers, measures where it sits relative to the cell (bounding-box alignment), and then
requires **XOR = 0 on every layer** before accepting it. For TOP's own shapes it finds the
template layer that XORs to zero against each wafer layer. Anything it cannot trace stops
it, and `placements.json` is not written. That is how it found the one design in
`../designs/` that did not match the wafer (§4.2).

What "identical" means in 01d's check, and why:

- **cells, TOP's shapes, the flattened wafer**: XOR = 0 per layer, same polygon counts.
- **placements**: cell, mirror, magnification and integer-dbu displacement exact; angle
  within 1e-9°. KLayout stores a rotation as sine/cosine and recomputes the GDS angle on
  write, which can move it by one unit in the last place (276.751004645 →
  276.7510046450001): ~1e-13 µm at the rim, invisible on a 1 nm grid, and check 4 proves it.
- **bytes**: reported, not required. GDS carries timestamps and the writer's record order.

**Revising content.** A revision config points `SOURCES` at the new files and reuses the old
wafer's `placements.json`. 01d notes every swapped source, builds with the new ones and still
checks against the old wafer, with three settings that make the check mean something:

- `EXPECTED_CHANGED_LAYERS` — differences on these layers are reported, not failed; any other
  difference still fails.
- `CHANGES_WITHIN` — per device cell, the change on a layer must lie inside another layer
  (Rev3: the changes on 3 and 8 inside the Metal2 pads, layer 6). A revision meant to touch
  only the pads therefore cannot touch anything else unnoticed.
- `EXTRA_TOP_LAYERS` — template layers added to TOP (Rev3: layer 8, Metal3's marks).

Placements must still match exactly.

---

## 4. Worked examples

### 4.1 `config.py` — 3 connector designs, seeded (re-run 2026-10-07)

4 × `12Block_56_15` + 8 smalls (4 × `51_35`, 4 × `71_15`, sharing one slot), seeded from
`reference_run_2026-07/`.

| | |
|---|---|
| Footprints | **no longer** match `reference_run_2026-07/`: the designs were revised after that nest (8-block 26 mm² smaller, 0.8 mm shorter at the board end). The current DXFs do match the fabricated cells |
| Nest | feasible on the first polish from the seed, 77 s |
| Clearances achieved | gap 0.057 mm, edge 3.027 mm, marks 3.162 mm |
| Wafer | 12 instances; layers 1/0, 3/0, 5/0, 6/0 (pre-renumbering, §6.1); max radius 46.958 mm; all checks passed |

Output: `runs/interconnect_4x3/`. (Run before the 51_35 bulb fix in §4.2; re-run 01–04 to
pick it up — gotcha 2.)

### 4.2 `config_rev2.py` — the fabricated Rev2 wafer

Target `MEA1K_wafer4_12x_8x_8x_breakoutboards_Rev2.gds` (byte-identical to
`../reference/WaferWith12_ALLNEW.gds`): 4 + 4 + 4 connectors and 26 dummies, 38 placements.

What 01c established, each by XOR = 0:

| Wafer part | Source | How |
|---|---|---|
| `CONN_BIG_NEW`, `CONN_SMALL_51_35_NEW`, `CONN_SMALL_71_15_NEW` | `../designs/*_chamfered_*.dxf` | DXF map metal1 → 7, polyimide_negative + etchingpad → 3, etching + via → 5, metal2 → 6; cell sits **−90 µm in y** from the DXF |
| `dummy_61_10_NEW`, `dummy_35_36_NEW` | `../designs/dummy_*_padrows.gds` | layers 1 → 3, 3 → 7 (5, 6 unchanged); no offset |
| TOP's own shapes | `new_wafer_actually.GDS` | template layers 3, 5, 6, 7, 10 kept as-is; 1/0, 8/0 and the off-wafer cluster dropped |

Found along the way: the shipped `51_35` DXF had **one** right-neck bulb where the
fabricated cell has **two** — `N_RIGHT_BULBS` is now 2 in `../config_8block.py` (1 for the
`71_15` variant; `../HANDOVER.md` §4.4). And the wafer carries one **duplicate placement**:
two `dummy_61_10_NEW` at (42.779, −9.325) mm, 31°. 01c warns, and 01d keeps it, since the
job is to reproduce the wafer.

01d result: all cells and TOP OK, 38/38 placements with positions exact and worst angle
deviation 5.7e-14°, flattened XOR 0 on 3/0, 5/0, 6/0, 7/0, 10/0 → `GEOMETRY IDENTICAL`.
Not byte-identical. Negative test: rebuilding with the old one-bulb DXF fails on exactly
that cell (574 095 µm² on 3/0) and on the flattened 3/0 (4 × that).

Output: `runs/wafer4_rev2/`.

### 4.3 `config_rev3.py` — the Rev3 wafer (built 2026-10-07)

The Rev2 wafer with the Rev3 pad stack (`../HANDOVER.md` §4.5): the PI etch squares become
perimeter etch vias on layer 3, and a new Metal3 layer (the pad squares) goes on layer 8.
Sources: `../designs/rev3/*_rev3.*` from `build_designs.py --rev 3`. Layer maps: Rev2's plus
`metal3 → 8` (DXF) and `8 → 8` (dummy GDS); the etch circles need no entry, since they are on
Polyimide_Negative / dummy layer 1, already mapped to 3.

**Metal3's alignment mark.** Template layer 8 holds a small (non-inverted) vernier in the
third of the five mark slots, between Etching's (slot 1) and PI's (slot 4) inverted marks,
plus the coarse marks every layer repeats. Rev2 dropped template layers 1 and 8, so both of
their slots were free; Rev3 keeps layer 8 as-is (`EXTRA_TOP_LAYERS`). Slot 2 (template
layer 1) is still free. The nearest device is as far from the new marks as from Rev2's
(0.5–1 mm on the right, 1–1.5 mm on the left).

01d result: all cells and TOP OK, changed as expected on 3/0 and 8/0 with every change
inside the Metal2 pads; 38/38 placements exact; flattened XOR 0 on 5/0, 6/0, 7/0, 10/0;
68.45 mm² on 3/0, 78.62 mm² on 8/0. 01e: the same XOR areas in the overlay.

Output: `runs/wafer4_rev3/` (`wafer_wafer4_rev3.gds`, `overlay_wafer4_rev3.gds` + `.lyp`).

---

## 5. Adapting it

### 5.1 Inspect a DXF first

Two reader assumptions fail **silently** — a plausible wrong footprint, no error:

- **Units must be micrometres.** A 50 × 15 mm part reads ~50000 × 15000. Ignore
  `$INSUNITS`; it is frequently wrong.
- **Only LWPOLYLINE and HATCH are read** by stage 01. CIRCLE, ARC, SPLINE and INSERT are
  invisible and must be exploded first. (KLayout, which 03/01c/01d use, reads everything.)

`../03_inspect.py <file.dxf>` prints the per-layer census and bbox.

### 5.2 A new nest config

Copy `config.py`, then set `RUN_TAG`, `DESIGNS` (`key`, `dxf`, `kind`, `count`), `LAYER_MAP`
and `SEED_MODE`. Designs sharing a `kind` are nested against their union envelope and are
interchangeable at export — group only near-identical shapes; stage 01 prints the waste.
**Any layer not in `LAYER_MAP` is silently deleted on export.**

Seeding dominates runtime (free nesting was ~20× worse on the 4 + 8 case). `"seeded"` also
puts a piece the seed has no pose for into the slot of a seed piece not placed this time.

### 5.3 A new wafer revision that keeps the layout

Copy `config_rev3.py`: point `PLACEMENTS_PATH` at the 01c output of the wafer to start from,
`SOURCES` at the revised designs, and list the layers the revision is meant to change in
`EXPECTED_CHANGED_LAYERS` (and where, in `CHANGES_WITHIN`). Run 01d, then 01e to look at it.
To start from a wafer other than Rev2, first write a reproduce config for it like
`config_rev2.py` and run 01c. To *move* or *add* pieces, edit `placements.json` (or the
script that writes it) — 01d builds whatever it says.

### 5.4 Check each stage before moving on

| After | Confirm |
|---|---|
| 01 | area and bbox as expected; overlay shows one closed outline; no "disjoint parts" warning |
| 02 | feasible; achieved gap / edge as asked; preview sane |
| 03 | `DROPPED` lists only layers you meant to drop |
| 04 | `ALL CHECKS PASSED` |
| 01c | every cell `OK`, every TOP layer matched, `wrote placements.json` |
| 01d | `GEOMETRY IDENTICAL`; for a revision, `IDENTICAL … except the expected changes on …` |
| 01e | XOR (datatype 2) empty on every layer the revision did not touch |

---

## 6. Open items

### 6.1 `config.py`'s `LAYER_MAP` is not the fabricated numbering

It writes polyimide_negative/etchingpad → 1, metal1 → 3, etching/via → 5, metal2 → 6. The
fabricated wafer has them on 3, 7, 5, 6 (renumbered by hand to sit on the matching mark
layers; `config_rev2.DXF_LAYER_MAP` is the fabricated one). A wafer nested with `config.py`
lands on the wrong masks until this is reconciled.

### 6.2 The nest path has no dummies

Dummies are GDS and stages 01/03 read DXF, and the Rev2 dummies were hand-placed in the gaps
after nesting. For a *new* layout they need a fill stage (pack into the leftover area under
the same clearances); for the Rev2 layout the reproduce path already has them.

### 6.3 Two WaferNesting forks

| | here | `generative_probe_design/WaferNesting/` |
|---|---|---|
| 00, 01, `footprint_extract.py` | — | same code (88–99 % of lines identical) |
| 03, 04 | basic | superset: mark inversion, OASIS/.lyp, placement record, mark checks |
| nester | `02_nest.py` (SA, fixed N, seeded) | `nest_tiler.py` (skyline, maximises N) |
| reproduce path | 01c, 01d, `exact_io.py` | — |
| map | — | `05_map_wafer.py` |

They also disagree on **mark polarity**: the probe fork copies an inverted vernier into
every dark-field mask; the fabricated interconnect wafer carries the template's marks
unmodified. A merged WaferNesting has to make that a per-wafer setting, not a default.

### 6.4 `config_electrode_bundle.py` is legacy

It expects `../electrode_bundle/designs/`, which does not exist here, and nests a single
probe with this folder's annealer. Probe wafers are made with the other fork. Kept only
because `runs/electrode_bundle_IONP_id11/` came from it.

---

## 7. Gotchas

1. **Any DXF layer missing from `LAYER_MAP` is silently deleted on export** (nest path).
   Stage 03 prints mapped and dropped layers per design; read them. Stage 04's per-layer
   count check is the backstop. This is how `EtchingPad` was nearly lost on the 2026-07 wafer.
2. **Never reuse poses because a footprint "did not change".** Regenerated designs once
   differed by 0.2–1.0 mm², visually identical, enough to drop old poses to a 0.0002 mm gap.
   Re-run 01 and 02 whenever a DXF changes.
3. **Never radius-check these pieces by bounding box.** They are bottle-shaped; a rotated
   piece's bbox overstates its reach by > 10 mm. Stage 04 uses the convex hull.
4. **`ENVELOPE_SIMPLIFY` must stay ≤ `ENVELOPE_PAD`**, or the envelope cuts inside its own
   members; stage 01's coverage assertion catches it.
5. **`extract()` is lossy on purpose** — it bridges splits up to 2 × `CLOSE_GAP` and keeps
   only the largest part of a disjoint result (§3.2).
6. **`runs/` is disposable; `reference_run_2026-07/` is not.** Nothing regenerates the seed.
   `runs/wafer4_rev2/` is regenerated by 01c + 01d, `runs/wafer4_rev3/` by
   `build_designs.py --rev 3` + 01c + 01d + 01e.
7. **SA is stochastic.** If a run stalls, change `RNG_SEED` or raise `RESTARTS` / `ITERS` —
   after checking the clearances (§3.3).
8. **Stages 01c, 01d, 01e, 03, 04 run under KLayout's Python** (no shapely / numpy / matplotlib).
   Keep configs and `exact_io.py` pure standard library + `pya`.
9. **Units:** µm in the DXFs, mm in the nest path, dbu (1 nm) in KLayout and in
   `placements.json`.
10. **01c measures offsets by bounding box.** A source whose bbox differs from the cell's
    (an extra or missing feature at the edge) gets a wrong offset and then fails its XOR —
    the failure is reported per layer, so look at which layer and where before suspecting
    the offset.

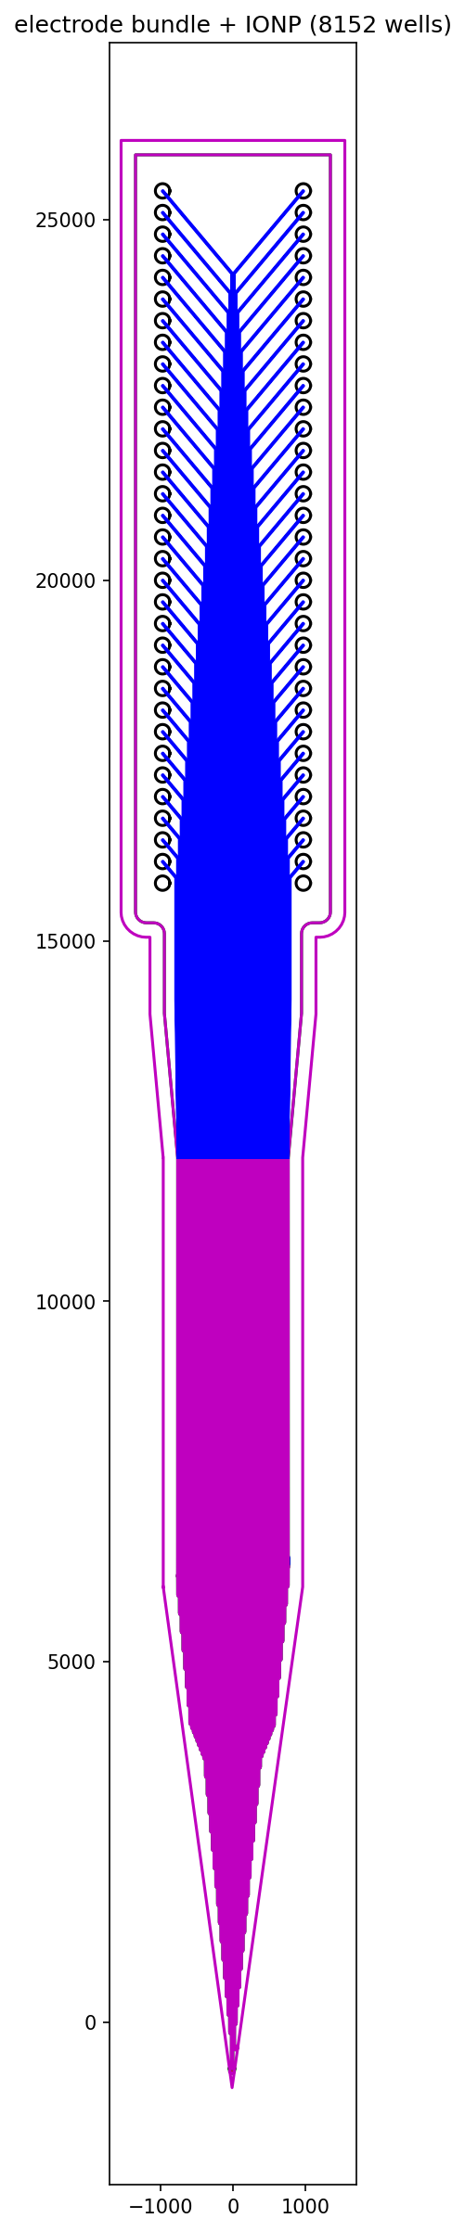
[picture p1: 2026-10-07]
generative_probe_design/electrode_bundle/designs/electrode_bundle_IONP_id11Example.png

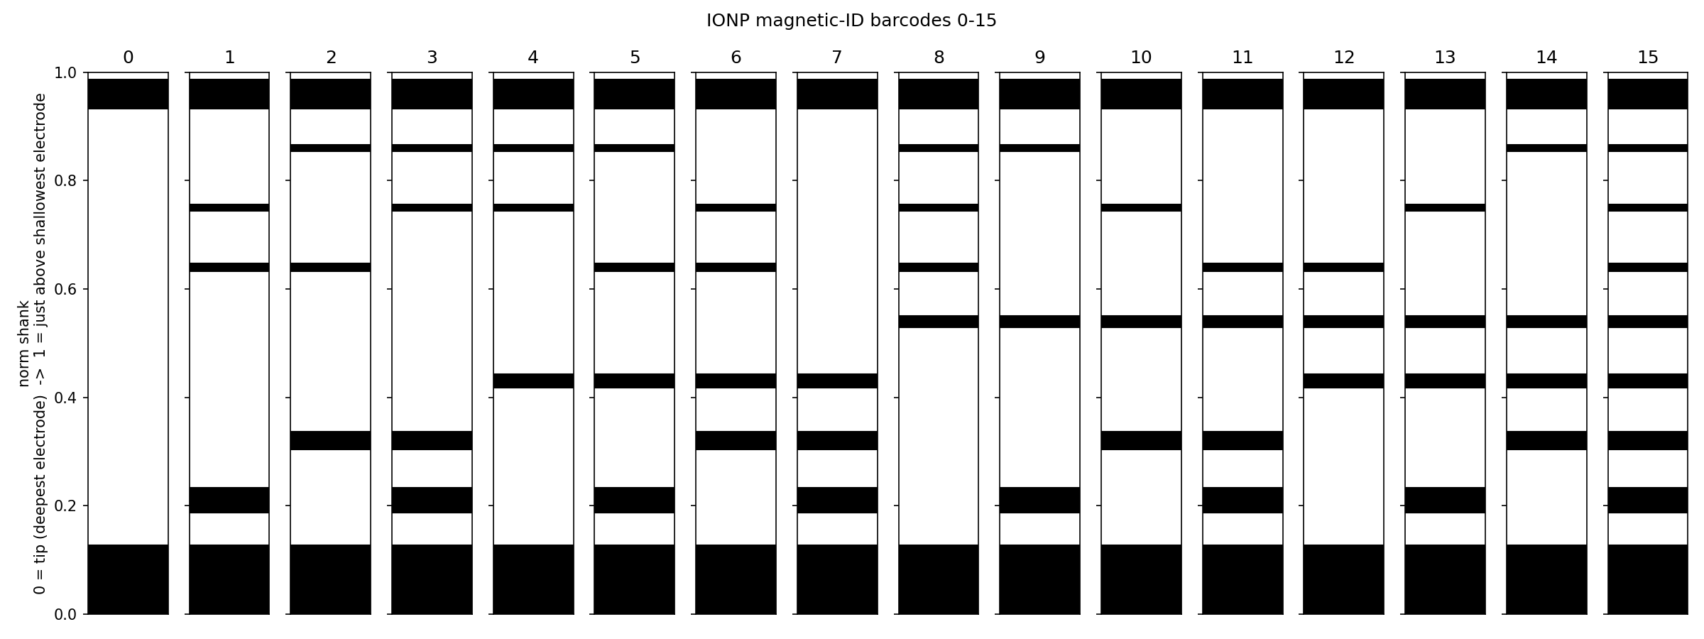
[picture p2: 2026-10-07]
generative_probe_design/electrode_bundle/designs/ionp_id_legend.png

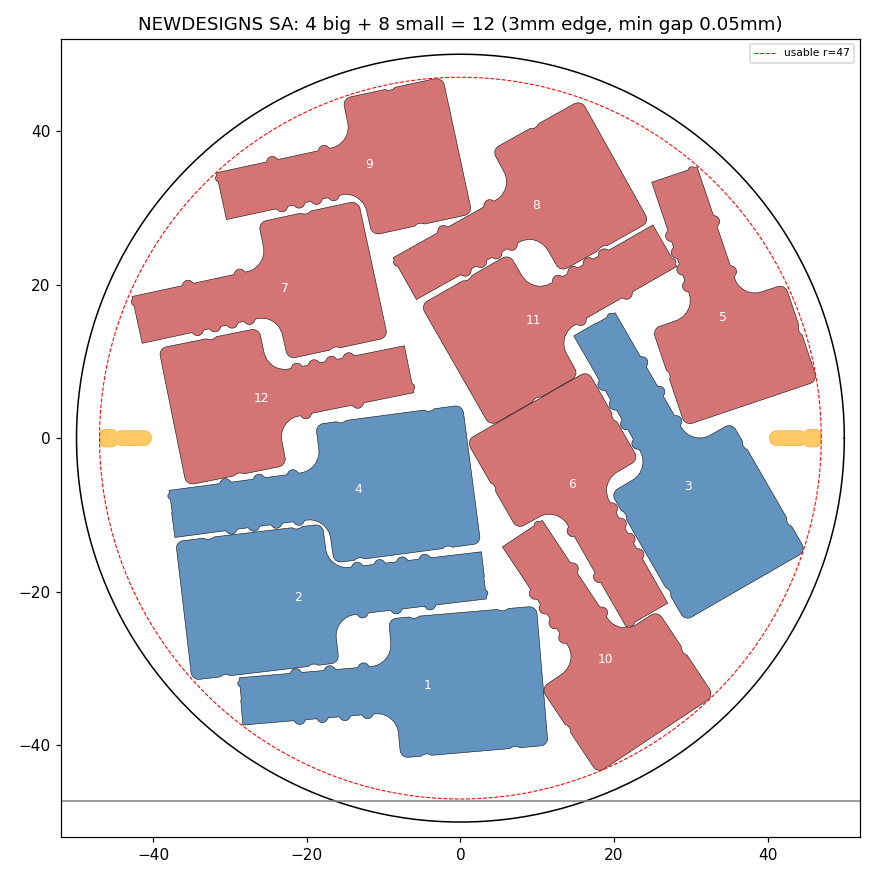
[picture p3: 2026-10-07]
InterconnectGeneration/WaferNesting/reference_run_2026-07/wafer_new_4x3_final_preview.png

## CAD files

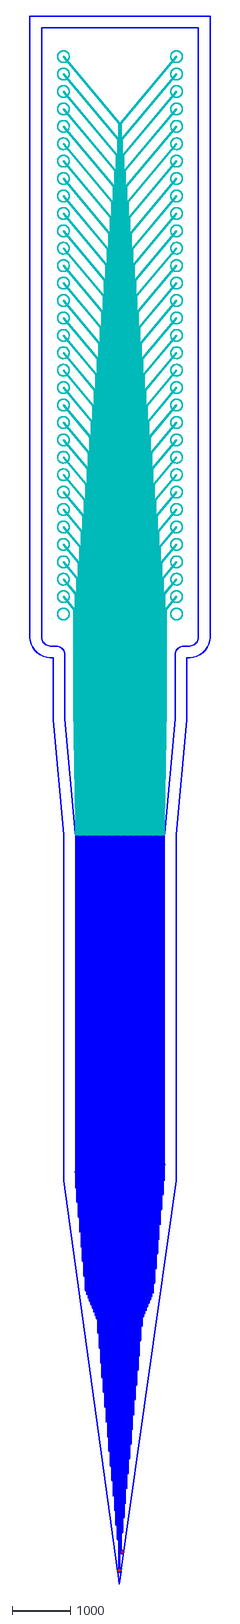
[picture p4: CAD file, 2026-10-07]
generative_probe_design/electrode_bundle/designs/electrode_bundleExample.dxf
3100.0 x 27004.0

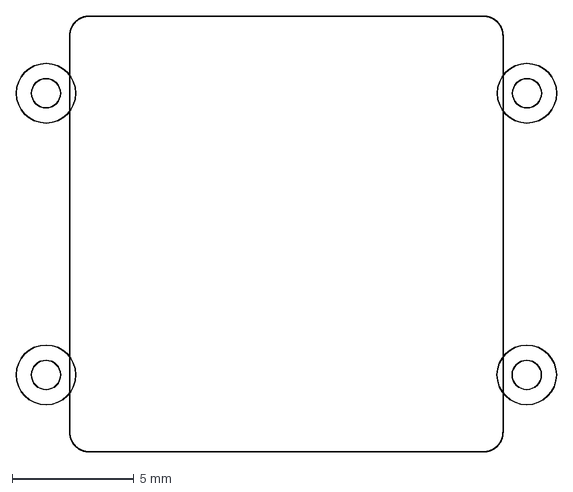
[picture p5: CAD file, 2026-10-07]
InterconnectGeneration/assets/Board_12x_outline_simon.dxf
22.2 x 17.9 mm

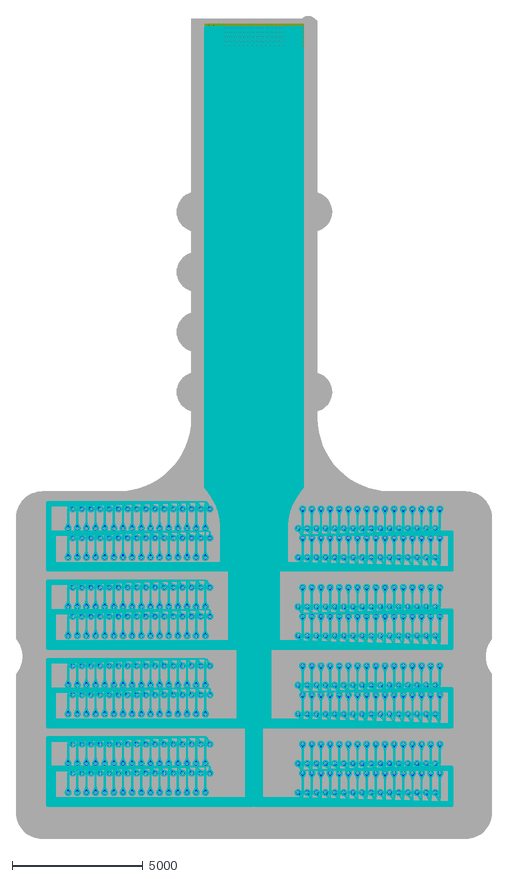
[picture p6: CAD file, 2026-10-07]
InterconnectGeneration/designs/new_interconnect_with_connector_8blocks_chamfered_1layer_51_35.dxf
18200.0 x 31490.1

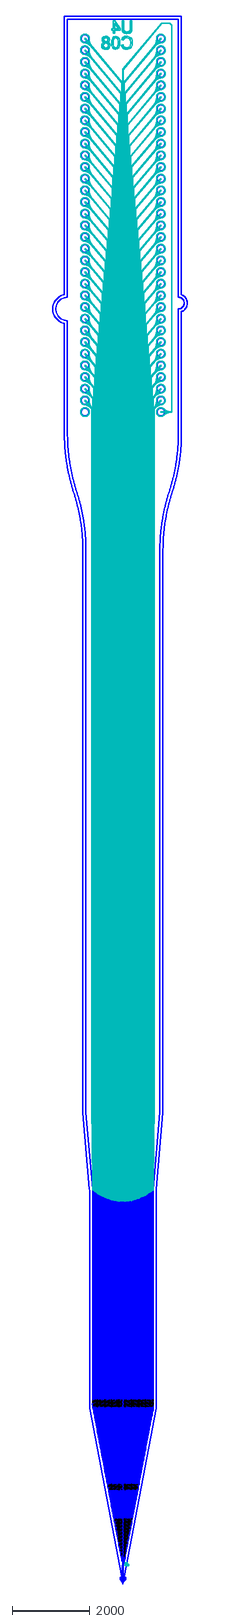
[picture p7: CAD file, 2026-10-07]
InterconnectGeneration/electrode_bundle_U4C08.dxf
3460.2 x 40300.0

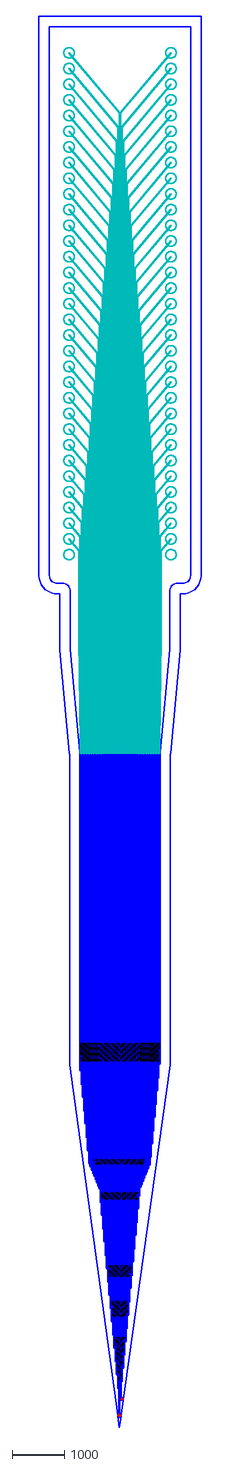
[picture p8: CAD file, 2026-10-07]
generative_probe_design/electrode_bundle/designs/electrode_bundle_IONP_id11Example.dxf
3100.0 x 27004.0

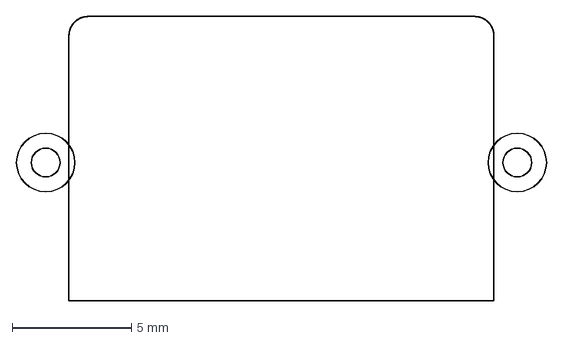
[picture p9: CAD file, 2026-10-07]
InterconnectGeneration/assets/Board_8x_outline_simon.dxf
22.2 x 11.9 mm

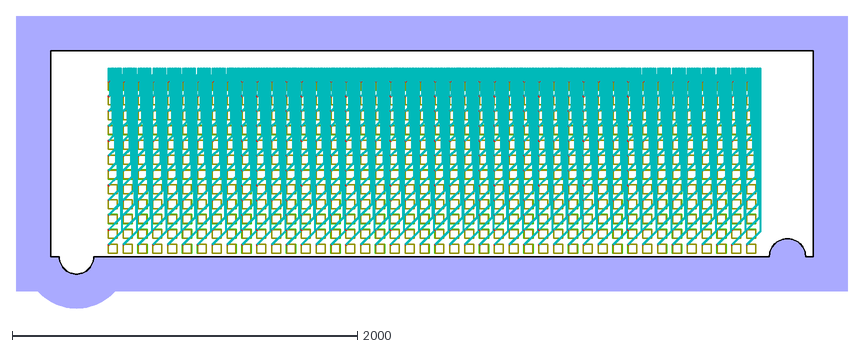
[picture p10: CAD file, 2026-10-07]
InterconnectGeneration/designs/new_interconnect_circular_8block_51_35.dxf
4819.0 x 1692.6

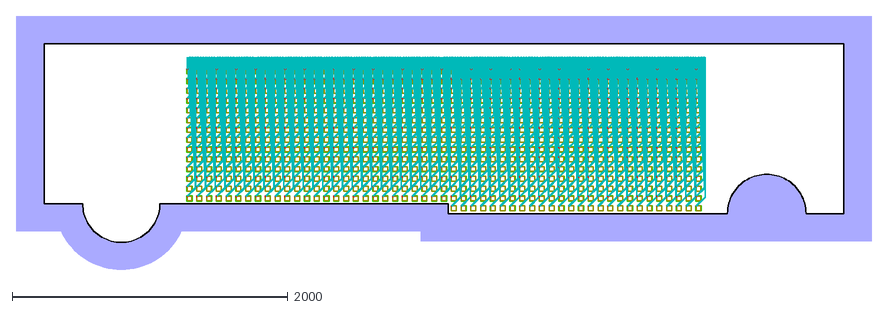
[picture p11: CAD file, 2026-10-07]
InterconnectGeneration/designs/new_interconnect_circular_dummy_35_36.dxf
6201.5 x 1841.6

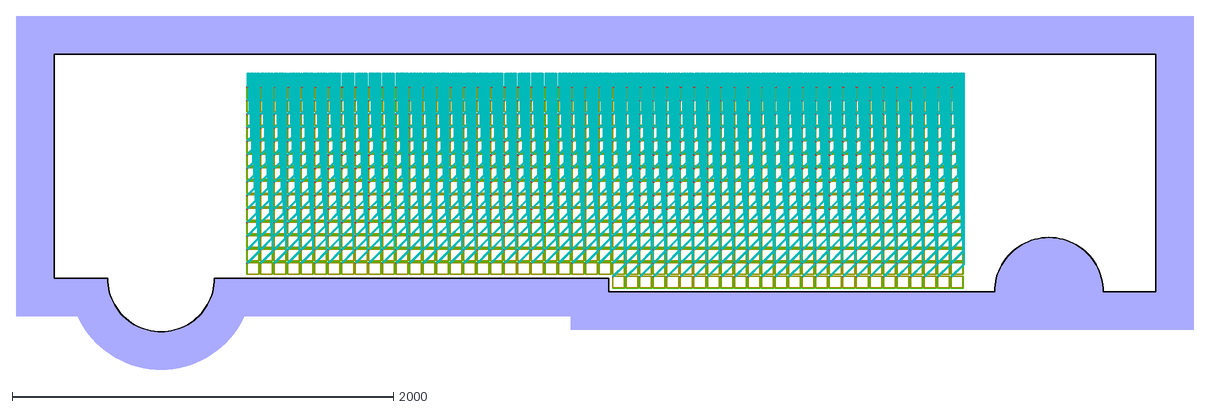
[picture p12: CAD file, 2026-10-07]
InterconnectGeneration/designs/new_interconnect_circular_dummy_61_10.dxf
6175.5 x 1854.6

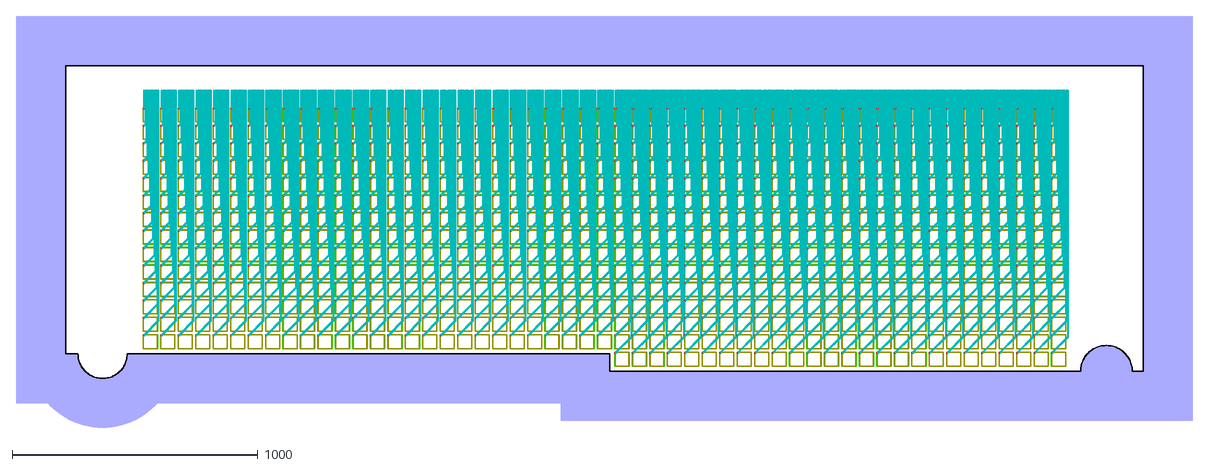
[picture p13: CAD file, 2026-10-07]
InterconnectGeneration/designs/new_interconnect_circular_12Block_56_15.dxf
4780.5 x 1672.1

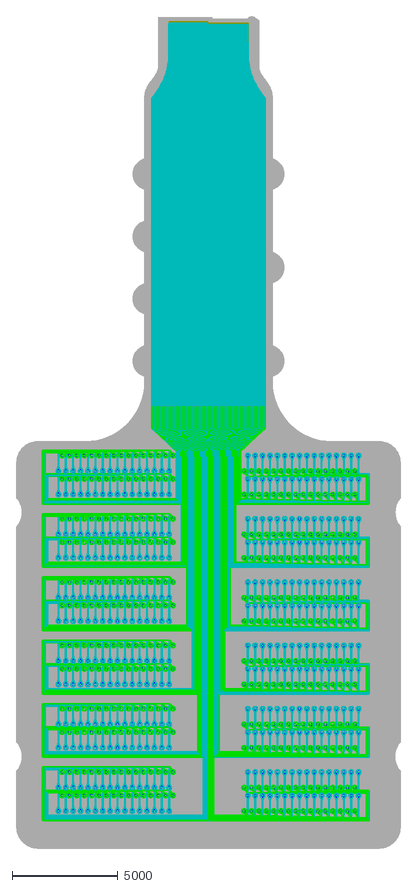
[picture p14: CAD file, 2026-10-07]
InterconnectGeneration/designs/new_interconnect_with_connector_chamfered_12Block_56_15.dxf
18200.0 x 39429.1

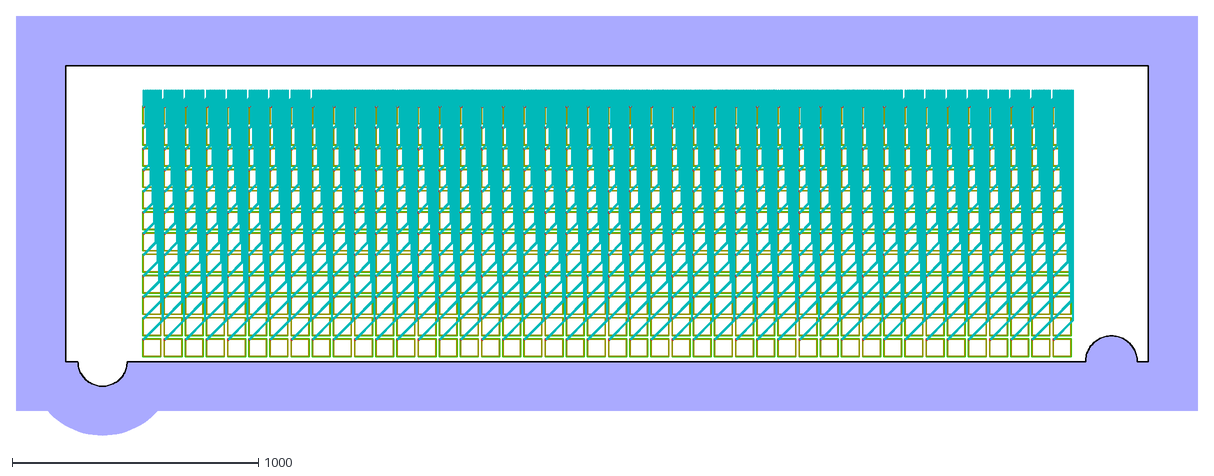
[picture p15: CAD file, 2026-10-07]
InterconnectGeneration/designs/new_interconnect_circular_8block_71_15.dxf
4799.0 x 1702.6

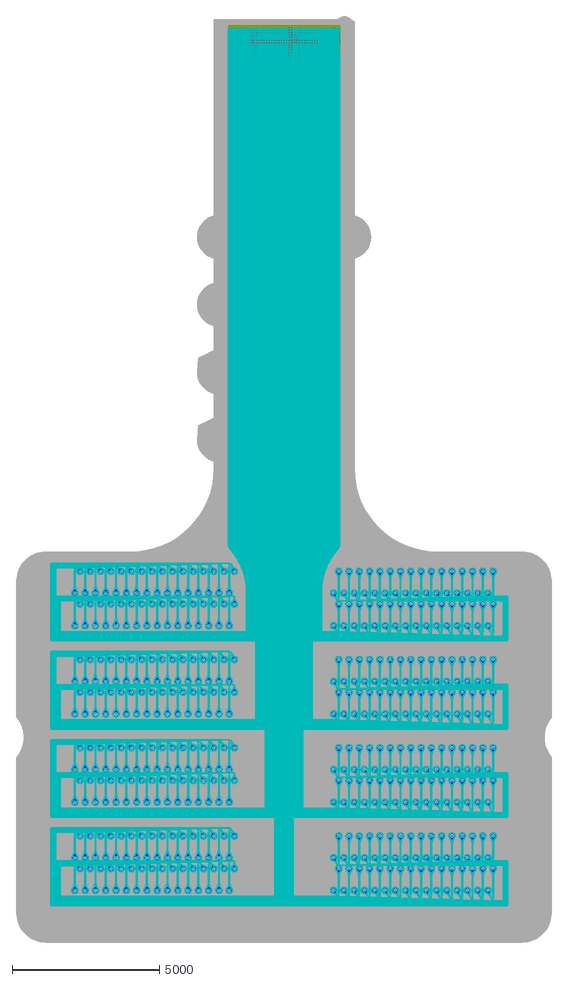
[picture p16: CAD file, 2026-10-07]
InterconnectGeneration/designs/new_interconnect_with_connector_8blocks_chamfered_1layer_71_15.dxf
18200.0 x 31500.1

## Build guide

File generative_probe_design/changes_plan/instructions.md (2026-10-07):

Plan to change the current generation of probes.

1. Change the hook design. Save the old (current ) hook in a suitable format in a different file. then create a new file with a new hook spec. the hook should look like the image new_hook.png. With one small change the 6 claps on the side should be wider. right now they are 2um, but they should be e5um in the new design.

2. change the electrode shape. Right now it's a square with rounded edges. make it compeltely round and smooth the polyimide as in the image: new_circular_electrode.png 

3. We need to integrate the IONP patterns. it's not yet settles how we do it. generate a random design, should one design spec have different IONP patterns etc. 

4. Small one: get rid of lollipop side hook. while doing this, also fix the etching surrounding. right now the hook is partly etched away, and in other regions this distance is unecessarily big. 

5. Mario already had something lkie this called roof. we want something similar, but probably a nonlinear folding funciton where the length of fibers & where they start doesn't just change at some regular step interval. But a v1 can use a linear adjustment here like the roof.  For  v2, check the image bundling_v2_better_roof.png. THis is the nonlinear version. it's based on this github repo: https://github.com/Neurotechnology-at-ETH-Zurich/electrode2geometry/
Extract the important part from it. it could even be a hardcoded adjustment specifically for the 64 channels we have as well. This changes how the design gets gets translated into a physical design. The json file should inidcate the y location of an electrode on the wafer, and then when bundled up. 

6. Big one: we want to not have a normal recording electrode on the central fiber with the hook, but instead expose contacts bewteen the hook and last reocrding el. these wide reocrding sites will be used as a Ref electrode. This unfortuantely has deep triclkle down effects up to the PCB. because the whole routing needs to fleip where (hopefully possible?) In that the bottom two contact pads right now are not being used, bc they are the Ref and Gnd pads of the  flexPCB. to route them to the center everything needs to be flipped. but that's just an inversion in channel ordering, so can be recovered afterwards. in anycase, how those Ref istes exactly get exposed needs to be defined in some spec as well, buut will be shared across all probes.

---

## Status (2026-10-05) — all six items have landed

1. **Hook** — done. The old hook is archived as `electrode_bundle/hooks/legacy_barb.py`; the
   new one is the parametric `electrode_bundle/hooks/teardrop_clap.py` (5 µm claps). Picked by
   `BundleConfig.hook`. Brief: [`BRIEF_tip_geometry.md`](BRIEF_tip_geometry.md).
2. **Circular electrode** — done: round opening / coating / gold pad with a smooth polyimide
   swelling (`shapes.create_polyimide_outline`). Same brief.
3. **IONP patterns** — done, though not as first briefed: a frozen bank
   (`electrode_bundle/ionp_patterns.py`), four ids per geometry, every geometry built in four
   barcoded variants. Brief (superseded): [`BRIEF_ionp.md`](BRIEF_ionp.md).
4. **Lollipop hook removed, etch surround fixed** — done; the probe has one etch hole, the loop.
5. **Bundling ("roof")** — done as `electrode_bundle/bundling.py` (`TwoArcFold`, after
   electrode2geometry). It staggers each fiber's shoulder, and `<name>_electrodes.json` records
   every electrode's wafer **and** bundled y.
6. **Ref electrode on the centre fiber** — done: 65 fibers, Ref contacts in two bands, routed
   over the top of the pad field to flex pad 66. Brief: [`BRIEF_ref_electrode.md`](BRIEF_ref_electrode.md).

Current state of all of it: [`../electrode_bundle/HANDOVER.md`](../electrode_bundle/HANDOVER.md).

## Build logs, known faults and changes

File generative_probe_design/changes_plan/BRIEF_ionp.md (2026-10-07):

# Brief: IONP barcode integration (plan item 3)

> **Status: superseded (historical record).** Written for the earlier 8-design set (C1–C4, H1,
> H2, 3140-8970, 980-6500), none of which exist any more. What landed instead: a frozen pattern
> bank in `electrode_bundle/ionp_patterns.py`, `DesignSpec.ionp_pattern_id` (one id per spec,
> not a `magnetic_ids` tuple), and `design_sets.DESIGNS` expanding each of the four current
> geometries into four barcoded variants via `ionp_patterns.DESIGN_IDS`. Step 2's two bugs were
> fixed (`config.variant_tag`; batch always writes the barcode-free DXF). For the current
> scheme read [`../electrode_bundle/HANDOVER.md`](../electrode_bundle/HANDOVER.md) §3.5 + §5.

Separate Claude Code session, run from `generative_probe_design/`.
Env: `source /opt/anaconda3/etc/profile.d/conda.sh && conda activate dxf`

**Stay out of** `shapes.py`, `bundle.py`, `mapping.py`, `bundling.py`, `lengths.py`,
`spacing.py` — other sessions own those. You own `ionp.py`, the IONP constants in
`config.py`, `magnetic_ids` on `DesignSpec`, and the id-expansion loop in `batch.py`.

Read `electrode_bundle/HANDOVER.md` §3.5 + §5 first, then `ionp.py`.

## Measured starting point

Every design × every id 0–15 was run. **The 700-well floor is never the problem** — min well
count across all 128 combinations is 700. Every failure is `min_strip_distance`:

| design | array span | ids passing |
|---|---|---|
| C1, C2, C3, H1, H2 | 5590–6655 | **16/16** |
| C4 | 4888 | **8/16** |
| 3140-8970 | 3140 | **2/16** |
| 980-6500 | 980 | **0** (id 0 "passes" only because its codeword is all zeros = no data stripes) |

## Do these four, in order

1. **`ID_TOP_ANCHOR_CENTER = 0.96 → 0.965`** in `config.py`. C4 goes **8/16 → 16/16**, and
   no other design regresses (margins improve on four of them). C4's failures were all the
   same single violation: top anchor 292.7 µm above the `0.86` data slot, needing 300. This
   is a tuning bug, not a short-probe problem. Do it first, independent of everything else.

2. **Fix two bugs that fire the moment any id is set** (both reproduced):
   - `batch.py` writes `electrode_bundle_{name}C{NN}.dxf` for id designs and never the
     plain path, but `side_by_side.py` reads `bundle_dxf_path(spec.name)` → `FileNotFoundError`,
     breaking the default `python3 -m electrode_bundle.batch`. Fix with a shared
     `variant_tag(name, magnetic_id)` helper in `config.py` next to `bundle_dxf_path`, and/or
     always write the barcode-free geometry DXF too.
   - Grown anchor bands are not clamped to `y_top`. On 980-6500 the top anchor reports height
     350.0 µm while `y_top` cuts it at 222 µm — `check_design_rules` and the info JSON both
     record geometry that is not what gets fabricated. Clamp, and make the report match.

3. **`DesignSpec.magnetic_id` → `magnetic_ids: Tuple[int, ...] = ()`.** One spec expands into
   N built artefacts rather than duplicating the geometry row per id. Keeps `DESIGNS` 1:1 with
   design-doc rows so `doc_id` provenance and single-source geometry survive. Validate range
   0–15 and reject duplicates in `__post_init__`. Add a `--ids` CLI override for exploration
   only — the committed spec is what records real hardware.
   **Leave all 8 real designs at `()`.** Do not invent ids for real hardware.

4. **Add a synthetic demo** so the barcode can be judged from pictures — plus run the existing
   `python3 -m electrode_bundle.main legend` (zero code, renders all 16 ids):
   ```python
   #NOT a doc row -- scratch geometry for eyeballing the barcode. Never fabricate.
   DesignSpec(name="DEMO", n_channels=64, sites=Uniform(span=6000),
              fiber_length=9000, loop_offset=445,
              overall_length=FAMILY_OVERALL_LENGTH,
              magnetic_ids=(1, 7, 11), doc_id="synthetic demo, not a doc row")
   ```

## Short probes — do NOT decide alone

`980-6500` (980 µm array) has capacity for **0** data slots and cannot carry a
distinguishable barcode under any combination tested. `magnetic_ids=()` with a comment
stating the number is the correct answer.

`3140-8970` fits 5 slots → a shortened A(5,3) code = **4 ids, still single-error-correcting**.
That is the principled degradation: you lose id space, not error correction.

**Ask the user before touching `min_strip_distance` (300 µm) or `ionp_well_distance` (5 µm).**
Relaxing 300 → 200 makes short probes pass but raises the stripe-misread rate the Hamming
code was sized against — it weakens the correction and the thing it corrects at once.
Denser wells are a fab/litho question, not a free knob.

## Done when

- all 8 designs still build; `python3 -m electrode_bundle.batch` (no flags) does not crash
- `python3 -m pytest electrode_bundle/tests -q` green (52 currently)
- a table of design × id pass/fail, before and after step 1
- DEMO renders shown to the user

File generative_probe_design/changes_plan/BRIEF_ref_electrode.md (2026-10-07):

# Brief: Ref electrode on the centre fiber (plan item 6)

> **Status: landed (historical record).** Closest to reading **B** below, plus a second band: the Ref has its own
> (centre, widened) fiber — a 65th, so all 64 recording channels are kept — with contacts in two bands (`config.RefSpec` / `REF_SITES`) — one
> below the deepest recording site running down the hook stem, one above the shallowest — on
> their own `Ref_Electrodes` layer, kept out of `BundleResult.electrode_locs` (they are in
> `ref_locs`). It is routed over the top to the **right** column's row 0, flex pad **66**
> (`shapes.REF_PAD`). The `mapping.py` assert on 65/66 still holds because the Ref is not a
> channel in the mapping. Current state:
> [`../electrode_bundle/HANDOVER.md`](../electrode_bundle/HANDOVER.md) §3.4.

**DO NOT START THIS UNTIL THE TIP-GEOMETRY SESSION (items 4/1/2) HAS LANDED.** It rewrites
`shapes.py` and `bundle.py` in the same places that session is editing.

Separate Claude Code session, run from `generative_probe_design/`.
Env: `source /opt/anaconda3/etc/profile.d/conda.sh && conda activate dxf`

Read `electrode_bundle/design_sets.py`'s module docstring first (labelled geometry diagram),
then `shapes.py` (`assign_channels_to_pads`, `build_pad_routes`, `build_pad_columns`),
`mapping.py`, and `MappingConfig` in `config.py`.

## The decisions, already made — do not relitigate

- **65 fibers**: 64 recording + 1 Ref. All 64 recording channels are kept.
- The Ref is the **centre fiber**, the one carrying the insertion hook.
- The flex PCB is **fixed** — REF/GND stay at the near end of each pad row. No re-spin.
- **Routing (the user's own words):** "route it to the left, up, next to other solder pads
  (but maximal distance) then enter from the top into the center."

## Why the obvious approach is impossible — do not try it

The plan originally assumed the routing could simply be inverted. It cannot. Each trace is a
vertical riser plus one diagonal at a fixed angle, so trace B's diagonal crosses trace A's
riser exactly when B goes to a lower pad than A. **Outer-lane → lower-pad is the ONLY
crossing-free ordering for this topology**, and this is a single-metal design with no
crossover layer.

Measured on the real route geometry:

```
CURRENT  assignment (outer lane -> lowest pad):    0 crossings
REVERSED assignment (inner lane -> lowest pad):  992 crossings   (= 2 x 32x31/2)
```

Also note: the centre fiber currently routes to **flex pad 2, the far end of the column from
REF/GND** — the worst-placed lane for this change.

## The route that does work

Planarity only forbids reaching the bottom pad *from the bundle side*. The Ref lane rises
past the top pad, jogs outward, descends **outside** the pad column, and enters REF/GND from
the top. It crosses nothing, because every other trace terminates at x = ±975 approaching
from the inside, and the region beyond is empty.

Verified there is room:

```
polyimide half-width  1350
pad centre             975  + pad radius 100  -> pad outer edge 1075
free corridor          275 um
headroom above top pad 400 um   (poly_block_top 25900 vs top pad edge 25500)
```

A 10 µm trace at 25 µm pitch fits ~10 such corridors, so one Ref lane is comfortable. Cost:
the Ref trace roughly doubles in length (~10.8 mm extra). Sanity-check series resistance
against your metal stack before committing — nobody has.

## Order of work — each step leaves the tree buildable

1. **Pin current behaviour first.** Add `tests/test_pad_assignment.py` asserting today's
   `assign_channels_to_pads` result (ch0→left/32, ch62→left/1, …) and the resulting flex pad
   numbers, plus a geometric no-crossing test over the routed centerlines. **Nothing guards
   this today** and it is the single source of truth for both geometry and mapping.
2. **Fix the n>64 crash.** `assign_channels_to_pads` splits at `n // 2`, so 65 lanes give one
   column 33 → `pad_row = 33` → `IndexError` on a 33-element list. Required for 65 fibers.
3. **Split `electrode_locs` into recording vs ref** in `BundleResult`, ref list empty for
   now. Update `lengths.measure`, `ionp.py`, `id_legend.py` and `probe_json.py` to use the
   recording list explicitly. **Output must stay bit-identical** — this is the de-risking
   step, do it before anything visible changes.
4. **Add the Ref spec.** The user said it is shared across probes, so a module-level constant
   (`REF_SITES = RefSpec(...)`), not a per-design field. Plus a `ref_channel` knob defaulting
   to off.
5. **Generalise `assign_channels_to_pads`** to take a set of ref channels and return
   `pad_row = 0` for them, keeping the monotone rule for the rest. With an empty ref set the
   output must be identical — assert that with the test from step 1.
6. **Add the wrap-around route** in `build_pad_routes` for `pad_row == 0`. Render and eyeball
   the corridor; assert clearance ≥100 µm from every pad edge and from the polyimide edge.
7. **Draw the Ref contacts.** Put them on their **own DXF layer**, not `Electrodes`, so
   `dxf_io.extract_electrode_centroids_from_msp` and the IONP path stay honest.
8. **Turn it on**, update `MappingConfig`, and extend the mapping JSON with `ref_channels` /
   `n_recording_channels` / `spare_pads`.

## The sleeper that will bite you

**`lengths.measure()` derives `sites.span` and `loop_offset` from `electrode_locs`.** If a Ref
contact stays in that array, every design's spec'd lengths silently change meaning and
`solve_lengths` will keep asserting success while solving for the wrong thing. This is why
step 3 comes before everything else.

Related: `mapping.py`'s `assert 65 not in used and 66 not in used, "REF/GND pad appeared in
mapping"` **will fire on every build** once the Ref is routed. It is currently correct; it
becomes wrong.

Also check with the tip-geometry session before starting: they changed the loop datum to a
DXF header variable (`LOOP_DATUM_VAR`), which `lengths.loop_y` and `side_by_side.datum_y`
both read. Do not reintroduce the old "lowest Etching entity" assumption — Ref contacts may
add etch openings.

## Where the Ref sites go — ask the user before writing geometry

"Expose contacts between the hook and the last recording el." Two readings, very different
cost:

- **A — in the gap ABOVE the centre contact.** Metal already runs there; you need extra
  `Electrodes`-layer openings plus a locally widened metal segment. Cheap.
- **B — BELOW the contact, toward the hook.** There is **no metal below the electrode pad
  today** (`create_metal_pad_wire_outline` only draws upward), and the polyimide there is
  only 20 µm wide, capping the site width unless `wide_wire_hw` grows — which pushes every
  other channel outward and widens the bundle.

The phrasing reads like B. Confirm which, and how wide/how many, before coding.

## Done when

- `python3 -m pytest electrode_bundle/tests -q` green
- all designs build; `python3 -m electrode_bundle.batch` does not crash
- a render showing the wrap-around, signed off by the user
- mapping JSON shows the Ref routed to pad 65, and 64 recording channels intact
  *(superseded 2026-09-17: the Ref was moved to the RIGHT column, so this is now pad 66 —
  `shapes.REF_PAD`. The rest of the brief still describes the wrap as built.)*

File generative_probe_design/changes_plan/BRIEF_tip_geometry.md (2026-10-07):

# Brief: tip geometry (plan items 1, 4, then 2)

> **Status: landed (historical record).** The lollipop/rescue hook is gone, the old hook lives
> on as `electrode_bundle/hooks/legacy_barb.py`, the new one is `hooks/teardrop_clap.py`, and
> the site is round. The loop datum is now `BundleResult.loop_xy`, stamped into the DXF header
> as `LOOP_Y_UM` — not "the lowest Etching entity". Line numbers and function names below
> (`shapes.HOOK_TEMPLATE`, `create_hook_polygon`, `rescue_hook_*`, `l = 13`, `l_contact = 11`)
> describe the code *before* this work. Current state:
> [`../electrode_bundle/HANDOVER.md`](../electrode_bundle/HANDOVER.md).

For a **separate Claude Code session**, run from `generative_probe_design/`. These items are
grouped because they all edit the same region of the same files and must not be done in
parallel with each other. Item 5 (bundling/roof) and the IONP + Ref-electrode analyses are
being handled elsewhere — don't touch `spacing.py`, `lengths.py`, `design_sets.py`,
`ionp.py` or `mapping.py`.

Start by reading `electrode_bundle/design_sets.py`'s module docstring — it has a labelled
diagram of the whole device and names every length parameter.

Environment: `source /opt/anaconda3/etc/profile.d/conda.sh && conda activate dxf`
Build + look: `python3 -m electrode_bundle.batch --no-render` then open
`64Ch_4Shankdesigns/shanks/all_designs_side_by_side.dxf`. Tests: `python3 -m pytest electrode_bundle/tests -q`
(44 currently pass — keep them passing).

---

## Do these in order: 4 → 1 → 2

Item 4 first because removing the lollipop simplifies the tip before item 1 reshapes it.

### Item 4 — remove the lollipop hook, fix the etch surround

The "rescue" hook is a lollipop on channel 1. Remove it and fix the etching:
> "right now the hook is partly etched away, and in other regions this distance is
> unnecessarily big."

Code:
- `shapes.create_rescue_hook_polygon()` (~line 448) and `shapes.rescue_hook_circle_centre()`
  (~line 498) — the shape and its etch-hole centre
- `bundle.py` ~lines 216-233 — where it is placed, and `rescue_etch`
- `config.BundleConfig` — `second_channel`, `hook_on_second_channel`, `rescue_hook_drop`,
  `rescue_hook_angle_deg`, `rescue_hook_arm_len`, `rescue_hook_circle_width`,
  `rescue_hook_circle_r`, `rescue_hook_etch_r`

**⚠ This breaks two things — they are not obvious and they are load-bearing:**

1. `lengths.loop_y()` finds the insertion loop as *"the LOWER of the two etch holes (the
   other is the rescue hook)"*. With only one etch hole left that comment is wrong and the
   `sorted(...)[0]` is fragile. `lengths.solve_lengths()` uses it to hit `fiber_length` and
   `loop_offset` exactly, and **every design's geometry is solved through it** — if the
   datum shifts, all 8 designs silently change length.
2. `side_by_side.datum_y()` uses the same "lower of two etch holes" assumption to align
   designs in the combined DXF.

Update both, and re-run the batch to confirm each design still reports its spec'd
`fiber_length` / `loop_offset` (there is a test, `test_lengths.py`, that pins this).

The etch geometry itself is `cfg.hook_etch_rx/ry/dx/dy` for the main hook — an ellipse
placed in `bundle.py` ~line 211.

### Item 1 — new hook

> "Save the old (current) hook in a suitable format in a different file. then create a new
> file with a new hook spec. the hook should look like `new_hook.png`. With one small change
> the 6 claps on the side should be wider. right now they are 2um, but they should be 5um."

Current hook is a **hardcoded 38-point coordinate template**, `shapes.HOOK_TEMPLATE`
(~line 411), normalised and placed by `shapes.create_hook_polygon()` (~line 427). It has
2 barbs. The new one (see `new_hook.png`) is different in kind:

- a bulbous **teardrop tip** rather than the current barbed arrowhead
- an **elliptical etch hole**, dimensioned 35 wide × 45.03 tall in the image
- **6 claps, 3 per side**, angled up and outward with rounded ends
- clap width **2 µm → 5 µm** (the `2.1257413` callout in the image is the current width)
- other callouts in the image: `7.1331745` and `5.885413`

"Save the old hook in a suitable format in a different file" maps naturally onto: move
`HOOK_TEMPLATE` out of `shapes.py` into a hook-spec module where each hook is a **named
spec** (template points or a parametric builder), so old and new coexist and a design can
choose. Consider whether the new hook should be parametric (clap count, clap width, tip
radii, etch ellipse) rather than another hardcoded point list — the user explicitly wants
one dimension tunable, which argues for parametric.

`hook_drop` must keep working: `lengths.solve_lengths()` tunes it to hit `loop_offset`, and
the relation is currently `loop_offset = hook_drop + 340.1` (linear, slope 1). The solve is
numeric so the constant may change freely, **but the relation must stay monotonic in
`hook_drop` with slope 1**, or `solve_lengths` will fail its assert. Also note the current
hook floor: `hook_drop=0` gives `loop_offset = 340.1 µm`, and the design doc has rows
wanting 280 and 320, which the current hook cannot reach. A smaller new hook may unlock
those — worth checking and reporting.

### Item 2 — circular electrode

> "Right now it's a square with rounded edges. make it completely round and smooth the
> polyimide as in `new_circular_electrode.png`."

- contact pad: `l_contact = 11` square → circle; `bundle.py` ~line 168
- metal pad under it: `l = 13` square → circle; `shapes.create_metal_pad_wire_outline()`
- polyimide around it: `shapes.create_polyimide_outline()` — the image shows a smooth
  lens/teardrop swelling rather than today's rounded square
- `config`: `metal_pad_arc_radius`, `contact_pad_arc_radius`, `polyimide_arc_radius` become
  meaningless for a circle — decide whether to keep them for other users or retire them
- `shapes.create_polygon_circle()` already exists (used for bond pads) — reuse it

Watch out: `ionp.drop_wells_near_contacts()` uses `keepout_radius` around contact centres,
and `lengths.measure()` derives the site span from `electrode_locs`. Neither should care
about pad *shape*, but confirm the span is unchanged after the switch.

---

## Definition of done

- `python3 -m pytest electrode_bundle/tests -q` still green
- `python3 -m electrode_bundle.batch --no-render` builds all 8, and each still reports its
  spec'd `fiber_length` / `loop_offset` / span
- the tip renders as in the reference images — **show the user a render and get sign-off
  before committing**, they asked to be in the loop on polyimide detail
- note anything that changed the loop datum, since that shifts every design's geometry

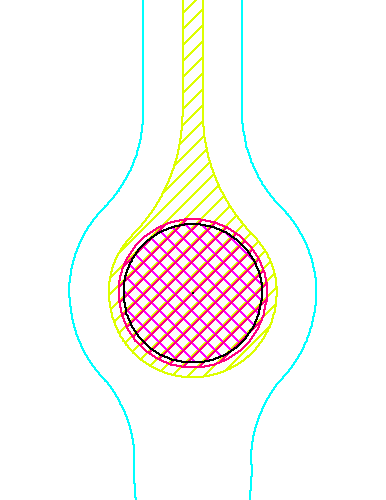
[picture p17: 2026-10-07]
generative_probe_design/changes_plan/new_circular_electrode.png

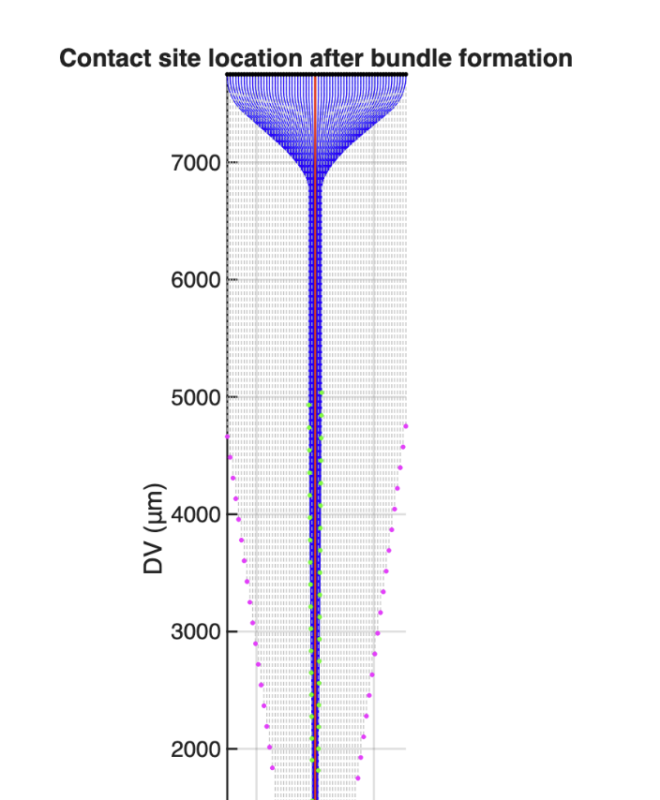
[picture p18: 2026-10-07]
generative_probe_design/changes_plan/bundling_v2_better_roof.png

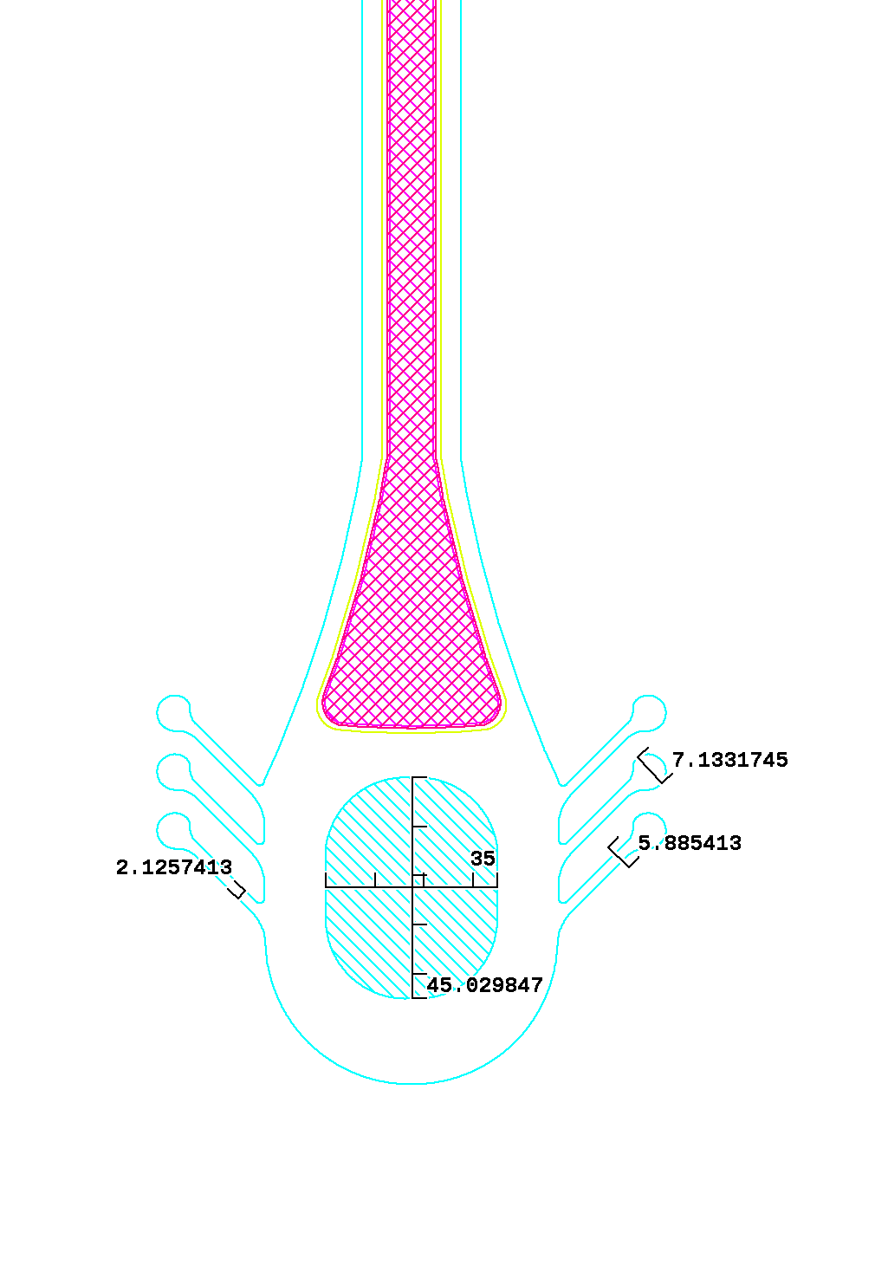
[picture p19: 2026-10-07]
generative_probe_design/changes_plan/new_hook.png

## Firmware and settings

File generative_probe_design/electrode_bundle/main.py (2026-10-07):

"""CLI entry point: one command for the whole electrode-bundle pipeline.

    python3 -m electrode_bundle.main all       # build + map + IONP, one in-memory pass
    python3 -m electrode_bundle.main bundle     # just the electrode bundle DXF + PNG
    python3 -m electrode_bundle.main mapping     # just the channel->flex JSON
    python3 -m electrode_bundle.main ionp        # stamp IONP wells onto the existing IONP DXF
    python3 -m electrode_bundle.main all --pattern-i 11   # pick magnetic-ID 0..15 (-> C11 output files)

`all` is the point of the consolidation: build the bundle ONCE and hand its in-memory
results (contact locations + channel->pad assignment) straight to the two consumers, so the
mapping never re-derives the routing order and IONP never re-reads the DXF or needs a rename.
"""
import argparse
import json

from .config import BundleConfig, IonpConfig, MappingConfig, ensure_out_dir
from . import bundle as bundle_mod
from . import dxf_io as io
from . import mapping as mapping_mod
from . import ionp as ionp_mod


def _ensure_usable_font():
    """Repair a truncated matplotlib font cache before drawing any text.

    Seen on macOS: ~/.matplotlib/fontlist-v*.json can be left holding only a partial scan
    (e.g. 35 system fonts, none of them the DejaVu Sans that ships WITH matplotlib). Every
    text draw then dies with "Failed to find font DejaVu Sans ... and fallback to the
    default font was disabled" -- matplotlib disables the fallback while resolving the
    default itself, so there is nothing left to fall back to. Rescanning fixes it and
    rewrites the cache, so this costs one slow run and never fires again.
    """
    from matplotlib import font_manager, rcParams
    have = {f.name for f in font_manager.fontManager.ttflist}
    if any(name in have for name in rcParams["font.sans-serif"]):
        return
    print("matplotlib's font cache lists no usable sans-serif font -- rebuilding it "
          "(one-off, ~10 s)")
    font_manager.fontManager = font_manager._load_fontmanager(try_read_cache=False)


def _save_png(result, out_png, ionp_xy=None, title=None):
    import matplotlib
    matplotlib.use("Agg")
    _ensure_usable_font()
    import matplotlib.pyplot as plt
    fig, ax = plt.subplots(figsize=(20, 20))
    bundle_mod.render_bundle(result, ax)
    if ionp_xy is not None:
        ax.scatter(ionp_xy[0], ionp_xy[1], color="blue", s=2, alpha=0.5)
    if title:
        ax.set_title(title)
    fig.savefig(out_png, dpi=150, bbox_inches="tight")
    plt.close(fig)
    print(f"Saved render -> {out_png}")


def _write_json(obj, path):
    with open(path, "w", encoding="utf-8") as f:
        json.dump(obj, f, indent=2)
    print(f"Wrote {path}")


def cmd_bundle(bcfg: BundleConfig, render: bool = True):
    result = bundle_mod.build_bundle(bcfg)
    io.save_dxf(result.doc, bcfg.out_dxf)
    print(f"Saved -> {bcfg.out_dxf}")
    if render:
        _save_png(result, bcfg.out_dxf.replace(".dxf", ".png"),
                  title=f"electrode bundle ({result.num_channels} ch)")
    return result


def build_mapping_summary(bcfg: BundleConfig, mcfg: MappingConfig, result=None):
    """The channel->flex-pad summary dict, without writing any file.

    Prefer the real assignment from a bundle build; else derive it standalone. Used both by
    the `mapping` subcommand (which writes the standalone JSON) and by the `all`/`ionp`
    pipelines (which embed it into the IONP info JSON instead)."""
    chan_pad = result.chan_pad if result is not None else \
        mapping_mod.standalone_chan_pad(mcfg.n_channels, bcfg.delta_x)
    return mapping_mod.build_mapping(chan_pad, mcfg)


def _print_mapping(summary, n_channels):
    for ci in range(n_channels):
        print(f"  ch{ci:>2} -> flex {summary['mapping'][str(ci)]:>2}")


def cmd_mapping(bcfg: BundleConfig, mcfg: MappingConfig, result=None):
    """Standalone `mapping` subcommand: no IONP info JSON exists here to embed into, so this
    is the one path that still writes electrode_to_flex_mapping.json."""
    summary = build_mapping_summary(bcfg, mcfg, result=result)
    _write_json(summary, mcfg.out_file)
    _print_mapping(summary, mcfg.n_channels)
    return summary


def cmd_ionp_standalone(bcfg: BundleConfig, mcfg: MappingConfig, icfg: IonpConfig):
    """Stamp wells onto an existing DXF (the old gen_ionp_bundle in-place behaviour)."""
    import ezdxf
    doc = ezdxf.readfile(icfg.dxf_file)
    msp = doc.modelspace()
    el_locs = ionp_mod.electrode_locs_from_dxf(msp, icfg)
    ionp_x, ionp_y, el_locs, pattern = ionp_mod.add_ionp_wells(doc, msp, el_locs, icfg)
    io.save_dxf(doc, icfg.dxf_file)
    print(f"Saved -> {icfg.dxf_file}")
    #No bundle result here; derive the mapping standalone and embed it in the info JSON.
    flex_mapping = build_mapping_summary(bcfg, mcfg)
    ionp_mod.write_pattern_summary_to_json(
        pattern, ionp_mod.effective_y_top(el_locs, icfg), icfg.y_bottom,
        el_locs, ionp_x, ionp_y, icfg, icfg.json_file, flex_mapping=flex_mapping)


def cmd_all(bcfg: BundleConfig, mcfg: MappingConfig, icfg: IonpConfig, render: bool = True):
    #1) build the bundle once
    result = bundle_mod.build_bundle(bcfg)
    #2) mapping from the same assignment the geometry used (embedded in the info JSON, not
    #   written as a standalone file)
    flex_mapping = build_mapping_summary(bcfg, mcfg, result=result)
    _print_mapping(flex_mapping, mcfg.n_channels)
    #3) IONP wells onto the same doc, from the in-memory contact locations (no DXF re-read)
    ionp_x, ionp_y, el_locs, pattern = ionp_mod.add_ionp_wells(result.doc, result.msp,
                                                               result.electrode_locs, icfg)
    #4) save the DXF (IONP superset) + summary (with embedded mapping) + render
    io.save_dxf(result.doc, icfg.dxf_file)
    print(f"Saved -> {icfg.dxf_file}")
    ionp_mod.write_pattern_summary_to_json(
        pattern, ionp_mod.effective_y_top(el_locs, icfg), icfg.y_bottom,
        el_locs, ionp_x, ionp_y, icfg, icfg.json_file, flex_mapping=flex_mapping)
    if render:
        _save_png(result, icfg.dxf_file.replace(".dxf", ".png"), ionp_xy=(ionp_x, ionp_y),
                  title=f"electrode bundle + IONP ({len(ionp_x)} wells)")
    return result


def cmd_legend():
    """Render the 16 magnetic-ID barcodes as a decode reference card."""
    from .id_legend import render_id_legend
    out_png = f"{ensure_out_dir()}/ionp_id_legend.png"
    render_id_legend(out_png)
    print(f"Saved legend -> {out_png}")


def _build_parser():
    p = argparse.ArgumentParser(description="Electrode-bundle pipeline")
    p.add_argument("command", choices=["bundle", "mapping", "ionp", "all", "legend"],
                   help="which step to run")
    p.add_argument("--pattern-i", type=int, choices=range(16), default=0, metavar="0-15",
                   help="IONP magnetic-ID pattern to stamp (0-15); sets the output filenames")
    p.add_argument("--no-render", action="store_true", help="skip PNG rendering")
    return p


def main(argv=None):
    args = _build_parser().parse_args(argv)

    print(f"Designs -> {ensure_out_dir()}")

    bcfg, mcfg = BundleConfig(), MappingConfig()
    icfg = IonpConfig(pattern_i=args.pattern_i)
    render = not args.no_render

    if args.command == "bundle":
        cmd_bundle(bcfg, render=render)
    elif args.command == "mapping":
        cmd_mapping(bcfg, mcfg, result=None)
    elif args.command == "ionp":
        cmd_ionp_standalone(bcfg, mcfg, icfg)
    elif args.command == "all":
        cmd_all(bcfg, mcfg, icfg, render=render)
    elif args.command == "legend":
        cmd_legend()


if __name__ == "__main__":
    main()

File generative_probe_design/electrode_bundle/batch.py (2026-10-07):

"""Build every design in design_sets.DESIGNS.

    python3 -m electrode_bundle.batch
    python3 -m electrode_bundle.batch --no-render

Each DesignSpec becomes one BundleConfig: `sites` resolves to the spacing knobs, then
`fiber_length`/`loop_offset` are solved for (lengths.py).

EVERY design writes the barcode-free geometry DXF at `bundle_dxf_path(name)` plus its
flex-pad mapping JSON and its `<name>_electrodes.json` record. A design that also carries an `ionp_pattern_id` then runs the same
in-memory `all` pipeline main.py uses (build once, mapping + IONP off the same result) and
writes a SECOND, barcoded DXF at the `variant_tag` path. Writing the plain DXF
unconditionally is deliberate: side_by_side.py reads exactly that path for every design and
used to crash with FileNotFoundError as soon as any design carried an id.

An id whose pattern does not fit the design's electrode array raises out of
`ionp.check_design_rules` -- run `python3 -m electrode_bundle.ionp_patterns` for the fit
table before adding one.

Entries share a `name` by design -- `DESIGNS` is four geometries x four barcode ids, so each
geometry appears four times. The barcode-free artefacts are written once per NAME, by the
first entry that uses it; the other three only build their barcoded DXF.

Finishes by writing TWO comparison drawings: `all_designs_side_by_side.dxf`, every distinct
GEOMETRY in a row barcode-free, and `all_ionp_patterns_side_by_side.dxf`, every barcoded
VARIANT in a row. The first says whether the shank shapes are right; the second is where you
check that the 16 stripe patterns are distinguishable from one another.
"""
import argparse
from dataclasses import replace

import numpy as np

from . import bundle as bundle_mod
from . import dxf_io as io
from . import shapes as sh
from .config import (BundleConfig, IonpConfig, MappingConfig, bundle_dxf_path,
                     ensure_out_dir, variant_tag)
from .design_sets import BUNDLE_FOLD, DESIGNS
from .lengths import solve_lengths
from .main import _save_png, _write_json, cmd_all, cmd_mapping
from .probe_json import build_record
from .side_by_side import build_side_by_side, dedupe_by_tag


def _target_positions(spec):
    """The contact y positions the spec asks for, as DRAWN on the wafer.

    Same frame and convention as the plain staircase: contact 0 sits at -(its own first
    gap), the rest accumulate upward. `config_for` draws exactly these -- the fold cost is
    absorbed by the staggered shoulder, not by moving contacts.
    """
    n = spec.n_channels
    if hasattr(spec.sites, "span"):
        delta_y = spec.sites.span / (n - 1)
        return np.array([(i - 1) * delta_y for i in range(n)], dtype=float)
    gaps = spec.sites.overrides(n)
    ys = [-gaps[1]]
    for i in range(1, n):
        ys.append(ys[-1] + gaps[i])
    return np.array(ys, dtype=float)


def _fiber_x(cfg, n):
    """Signed lateral offset of every FIBER, which is what the fold cost depends on.

    Fiber-indexed to match `BundleConfig.shoulder_offsets_profile`: index 0 is the
    reference on the centre slot, recording channel c is index c+1. Keep this in step with
    `shapes.fiber_x_positions` -- it feeds the shoulder stagger, which feeds the length
    solve, so a layout that disagrees here ships designs whose fibers are the wrong length.
    """
    chan_x, ref_x = sh.fiber_x_positions(n, cfg.delta_x, cfg.wire_hw, cfg.wide_wire_hw)
    return np.array([ref_x] + [chan_x[i] for i in range(n)], dtype=float)


def _channel_x(cfg, n):
    """Signed lateral offset of each RECORDING channel (the reference dropped)."""
    return _fiber_x(cfg, n)[1:]


def design_label(spec) -> str:
    """What gets stamped into the gold layer, e.g. "U8" or "U1.6\\nC01".

    The same string `variant_tag` builds ("U1.6C01"), broken over two lines: this one is
    read off a wafer under a scope, and the name stays legible on its own line above the
    IONP code. Keep the two in step -- matching a piece under the scope to its DXF is
    supposed to be reading, not decoding.
    """
    return (spec.name if spec.ionp_pattern_id is None
            else f"{spec.name}\nC{spec.ionp_pattern_id:02d}")


def config_for(spec) -> BundleConfig:
    """The BundleConfig a DesignSpec describes: sites at spec, shoulders staggered.

    `spec.sites` states where the contacts are DRAWN, and they are drawn exactly there --
    the staircase is the plain one `spacing.py` produces, untouched.

    The extra fiber each channel needs to reach the bundle is added at the TOP instead, by
    freeing that fiber from the polyimide block higher up: channel i's shoulder sits
    `BUNDLE_FOLD.offsets(x_i)` above the base, so its free fiber is that much longer. The
    centre fiber gains ~0 and the outermost gains the most (~282 um on C1), which is what
    makes the block's lower edge a staggered curve rather than a straight cut -- see the
    variable-shoulder surface in `bundle.py`.

    Note what this does NOT do: `bundling.offsets` is a function of lateral x alone, so under
    that model the bundled contact still lands at `drawn_y + offset` and the implanted array
    still comes out ~282 um longer than the drawn one. The stagger buys the outer fibers a
    longer, gentler run into the bundle; it is not a depth correction. `probe_json` records
    the bundled positions alongside the drawn ones so the difference stays visible.

    `shoulder_offsets_profile` is set BEFORE `solve_lengths` runs, so the solve measures the
    staggered build and `fiber_length` still lands on spec (measured loop -> block bottom,
    i.e. the top of the stagger, which is where the ribbon actually begins).
    """
    n = spec.n_channels
    probe = BundleConfig(num_channels=n)
    #each channel's fiber is freed this much higher up; index by channel, not by x
    rise = BUNDLE_FOLD.offsets(_fiber_x(probe, n))

    cfg = BundleConfig(
        num_channels=n,
        **spec.sites.delta_y_kwargs(n),
        shoulder_offsets_profile=lambda i, _r=rise: float(_r[i]),
        label=design_label(spec),
    )
    cfg = solve_lengths(cfg, fiber_length=spec.fiber_length, loop_offset=spec.loop_offset)

    if spec.overall_length is not None:
        #the ribbon absorbs whatever the fiber does not use, so designs with different
        #fiber lengths still end at the same connector position
        ribbon = spec.overall_length - spec.fiber_length
        if ribbon <= cfg.polyimide_fan_height:
            raise ValueError(
                f"{spec.name}: overall_length {spec.overall_length} leaves only {ribbon} um "
                f"of ribbon for a {cfg.polyimide_fan_height} um fanout -- it must exceed "
                f"fiber_length ({spec.fiber_length}) by more than that")
        cfg = replace(cfg, ribbon_length=ribbon)
    return cfg
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

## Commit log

2026-10-07 Initial import: InterconnectGeneration, generative_probe_design, Rev2 wafer
    InterconnectGeneration with its WaferNesting fork, including the exact-reproduce
    path (01c/01d/exact_io, config_rev2) that rebuilds the fabricated Rev2 wafer
    geometry-identically. generative_probe_design copied from ephysVR to be merged here.
    [Board_12x_outline_simon.dxf, Board_8x_outline_simon.dxf, connector_signal_pads_exact_mm.csv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]
2026-10-07 Rev3 pad stack: perimeter PI etch vias + Metal3, Rev3 wafer at Rev2 placements
    - stage 01: pad_etch='vias' replaces the EtchingPad square with via-sized circles around
    each pad perimeter on Polyimide_Negative (count per side from etch_via_spacing 15-20 um;
    the corner over the routing via left out); metal3=True repeats the pad squares on Metal3.
    Rev2 settings (square, no Metal3) rebuild all shipped designs geometry-identically.
    - build_designs.py: builds all five wafer designs of a revision; the HANDOVER 4.4 variant
    table and the revisions are data, so configs are no longer edited and reverted. Fails on
    router crossings / pad hits / FAIL lines.
    - WaferNesting: config_rev3 (Rev2 plac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
    [config.py]
